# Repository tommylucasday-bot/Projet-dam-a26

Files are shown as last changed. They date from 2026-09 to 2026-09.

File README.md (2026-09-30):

# Projet-dam-a26
## Distributeur automatique modulaire :

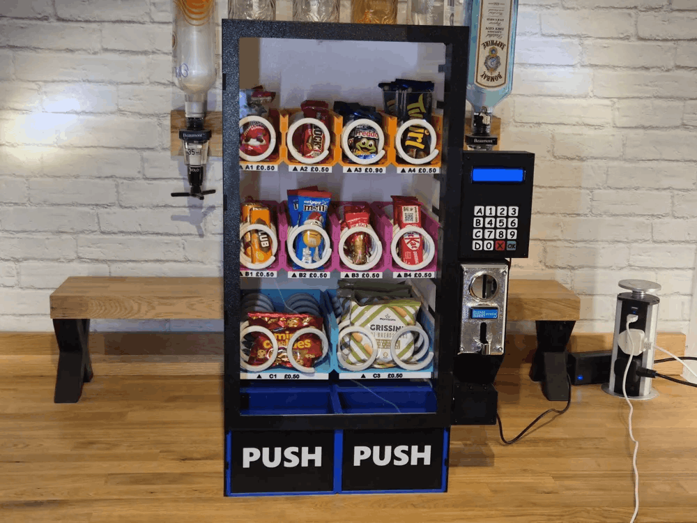
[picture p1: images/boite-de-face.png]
image-produit


### Contexte :
Dans le cadre du cours de planification de projet, nous devons réaliser un projet d’électronique pouvant être utilisé par les futurs étudiants afin de mettre en pratique diverses notions vues en classe.
### Objectif :
Ce projet a pour objectif de produire une machine distributrice automatique modulaire pouvant être personnalisée au gout du client que se sois selon la taille ou la couleur désirée mais aussi les moyens de paiements et les interfaces de contrôle désirés par celui-ci. 
### Structure du dépôt :
[Projet-dam-a26]    
- README.md  
- images  
  - Ensemble des images utilisées dans la documentation.     
- projet-original  
  - documentations  
     - Documentation originale fournie avec les fichiers originaux permettant la reproduction du projet.  
  - stl-originaux  
     - Accessoires  
       - Ensemble des fichiers 3d afin de produire les différents accessoires.  
     - Coils  
        - Ensemble des fichiers 3d afin de produire les différentes variantes de vis sans fin.  
     - Door  
       - Ensemble des fichiers 3d afin de produire les différentes pièces nécessaire pour la porte de la machine.  
     - Front Sides  
       - Ensemble des fichiers 3d afin de produire les différentes pièces nécessaire pour le devant de la machine.  
     - Keypad  
       - Ensemble des fichiers 3d afin de produire les différentes pièces nécessaire pour le clavier de la machine.  
     - Lid  
       - Ensemble des fichiers 3d afin de produire les différentes pièces nécessaire pour le couvercle de la machine.  
     - Module Sides  
       - Ensemble des fichiers 3d afin de produire les différentes pièces nécessaire pour les cotes de la machine.  
     - Modules  
       - Ensemble des fichiers 3d afin de produire les différentes pièces nécessaire pour les modules contenant les differents produits a vendre.  
- scrum  
  - carnet-de-produit  
    - Ensemble de la documentation expliquant la vision du projet et les diverses fonctionnalites prevus pour la machine.   
  - sprint-1  
    - Ensemble de la documentation expliquant l'objectif sur sprint 1, les diverses taches a effectuer et la rétroaction a la fin de celui-ci.  
  - sprint-2  
    - Ensemble de la documentation expliquant l'objectif sur sprint 1, les diverses taches a effectuer et la rétroaction a la fin de celui-ci.  
  - sprint-3  
    - Ensemble de la documentation expliquant l'objectif sur sprint 1, les diverses taches a effectuer et la rétroaction a la fin de celui-ci.  
  - LICENSE  

### Démarage
Afin de faire fonctionner le produit il suffira de le brancher a une source de tension 120v, de le remplir et d'indiquer les prix desirer pour les items a l'aide du code administrateur sur l'interface utilisateur.

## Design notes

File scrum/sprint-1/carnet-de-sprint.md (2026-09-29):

## Objectif du sprint
Concevoir un prototype fonctionnel de la machine distributrice permettant la sélection d'un produit, la gestion du paiement et la commande des différents moteur de distribution.

## Tâches 1 - Préparation du système de monnaie :
Installer le module pour le sytème de monnaie sur la machine distributrice.
Brancher et configurer le lecteur pour détecter chaque pièce insérée.
S'assurer que le détecteur de monnaie détecte bien la monnaie.

## Tâches 2 - Impression de la machine distributrice :
### Accesoires
- [ ] Imprimer l'objet : "Coin Reader"                       x1
- [ ] Imprimer l'objet : "Coin Tray"                         x1
### Coils
- [x] Imprimer l'objet : "Coil 5 Items Left Hand"            x1
- [x] Imprimer l'objet : "Coil 5 Items Right Hand"           x1
- [x] Imprimer l'objet : "Coil 6 Items Left Hand"            x1
- [x] Imprimer l'objet : "Coil 7 Items Left Hand"            x1
### Door
- [x] Imprimer l'objet : "Bottom Door Corner Hinge"          x1
- [x] Imprimer l'objet : "Door Straight Hinger"              x1
- [x] Imprimer l'objet : "Door Top Corner Hinge"             x1
- [x] Imprimer l'objet : "Door Top Corner Right"             x1
- [x] Imprimer l'objet : "Door Straight Latch"               x1
- [x] Imprimer l'objet : "Door Bottom Corner Right"          x1
- [x] Imprimer l'objet : "Door Glass Holder"                 x4
- [x] Imprimer l'objet : "Door Joiner"                       x6
### Front Sides
- [x] Imprimer l'objet : "Front Side Bottom Right"           x1
- [x] Imprimer l'objet : "Front Side Bottom Hinge"           x1
- [x] Imprimer l'objet : "Front Side Hinge v2"               x2
- [x] Imprimer l'objet : "Front Side Right Door Latch"       x1
- [x] Imprimer l'objet : "Front Side Right"                  x1
- [x] Imprimer l'objet : "Front Side Joiner Plate"           x4
- [x] Imprimer l'objet : "Joiner Front Side to Module Side"  x10
### Lid
- [x] Imprimer l'objet : "Front Lid Edge v2"                 x2
- [x] Imprimer l'objet : "Front Lid plate"                   x1
- [x] Imprimer l'objet : "Lid Edge v2"                       x2
- [x] Imprimer l'objet : "Lid Plate"                         x1
- [x] Imprimer l'objet : "Plate Joiner"                      x1
### Module sides
- [x] Imprimer l'objet : "Bottom Module Side"                x2
- [x] Imprimer l'objet : "Module Side"                       x4
### Module
- [x] Imprimer l'objet : "Back Stand"                        x2
- [x] Imprimer l'objet : "Double Label"                      x1
- [x] Imprimer l'objet : "Double Module"                     x1
- [x] Imprimer l'objet : "Module Joiner"                     x2
- [x] Imprimer l'objet : "Single Modules"                    x2
- [x] Imprimer l'objet : "Single Label"                      x2
- [x] Imprimer l'objet : "Push Bin"                          x1
- [x] Imprimer l'objet : "Push Flap"                         x1
- [x] Imprimer l'objet : "Single Back Plate"                 x2
- [x] Imprimer l'objet : "Single Back Plate Top"             x2
### Bonus Parts
- [x] Imprimer l'objet : "Adapteur Servo"                    x4
- [ ] Imprimer l'objet : "Adapteur Servo Connect"            x4

## Tâches 3 - Organisation des moteurs :
Fixer les moteurs de distribution et les ressorts sur leurs supports.
Cabler les moteurs aux circuits de commandes.
Programmer pour etre capable de faire tourner le moteur selon la distance voulue.

## Tâches 4 - Interface d'utilisateur :
Installer l'écran sur la machine distributrice et faire afficher la liste des produits et les prix.
Faire afficher un ecran d'acceuil de base pour le client.

## Tâches 5 - Relié les différentes taches pour obtenir un prototype fonctionnel :
Faire en sorte que les différents composants des tâches fonctionnent entre elle pour permettre une démo lors de la fin du sprint 1.

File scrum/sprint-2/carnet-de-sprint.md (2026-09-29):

## Tâches 1 - programmation du payement par carte :
Configurer le module de paiement pour compter les pièces ou lire la carte.
Calculer le total du crédit entré par l'utilisateur.
Gérer le rejet de la pièce ou le retour de monnaie si le montant dépasse le prix.
Ajouter un voyant lumineux et un signal sonore pour guider l'utilisateur.

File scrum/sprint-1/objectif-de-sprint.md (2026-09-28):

# Objectif de sprint

## Vision globale
Notre objectif est de reconstruire la machine distributrice en utilisant une imprimante 3d et de pouvoir la faire fonctionner.

## Ce qu'on veut accomplir
- Faire le boitier de la machine distributrice avec une imprimante 3d, celle-ci aura une porte avec une vitre pour pouvoir à l'intérieur.
- Faire l'impression des bacs pour les produits vendus, ressorts et ajouter des moteurs DC pour pouvoir faire tourner les ressorts pour faire dessendre les produits.
- Avoir une porte pour permettre la récupération des articles qui vont tomber.
- Avoir 3 boutons permettant la sélection des produits.
- Utilisation d'un écran affin d'afficher le prix des produits et permettre l'affichage des produits en rupture de stock
- Mettre en place un système de payment avec de la monnaie et une endroit pour stocker celle-ci.

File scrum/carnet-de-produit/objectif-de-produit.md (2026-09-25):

# Objectif de produit

## Vision globale
Notre objectif est de reconstruire la machine distributrice originale pour qu'elle fonctionne parfaitement, puis de l'améliorer pour la rendre plus pratique, autonome et facile à utiliser.

## Ce qu'on veut accomplir
- Avoir une distributrice fiable qui livre les produits sans bloquer.
- Ajouter une porte facile à ouvrir pour le remplissage et des capteurs fiables.
- Intégrer un système de paiement par carte avec des boutons de sélection.
- Brancher la machine directement sur une prise murale standard de 120 V.

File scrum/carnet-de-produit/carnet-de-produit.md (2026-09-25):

# Carnet de produit

## Sprint 1 : Projet original
- Monter et imprimer les pièces de base de la distributrice
- Faire le câblage et tester les moteurs
- Programmer le code de départ
- Faire la démonstration fonctionnelle au prof

## Sprints 2 et 3 : Nos améliorations
- Ajouter une porte sur charnières avec aimants pour faciliter le remplissage
- Mettre une plaque de pression pour détecter quand le produit tombe
- Ajouter un capteur pour avertir quand une rangée est vide
- Installer un bloc d'alimentation 120 V pour brancher dans le mur
- Ajouter un système de paiement par carte RFID
- Mettre des boutons pour sélectionner le produit
- Ajouter un écran simple pour l'utilisateur
- Mettre des pieds antidérapants pour stabiliser la machine

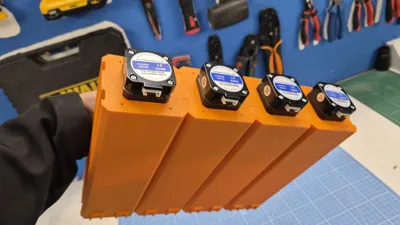
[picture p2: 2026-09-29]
images/bacs-et-moteurs.png

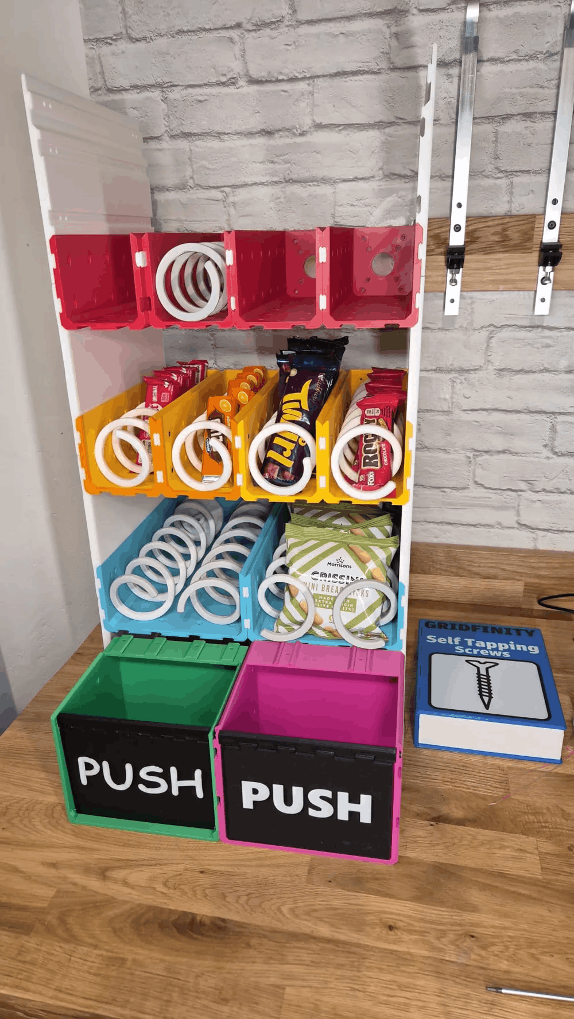
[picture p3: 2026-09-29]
images/distributeur-sans-boite.png

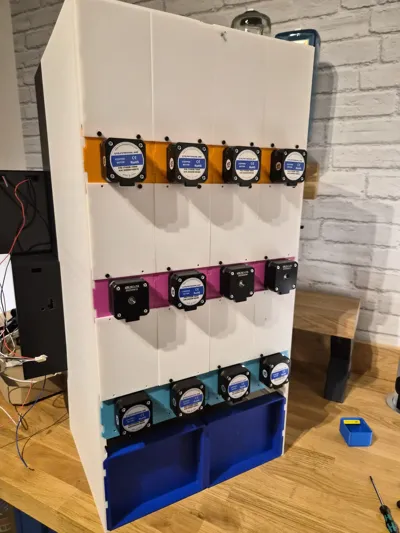
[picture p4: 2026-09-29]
images/boite-de-dos.png

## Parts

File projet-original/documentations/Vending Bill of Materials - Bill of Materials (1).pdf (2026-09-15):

Part | Type | Quantity | Price per Item | Total | Link
M2.5 x 5mm Self Tapping Screws | Fixings | 140 | £0.04 | £5.60 https://uk.store.bambulab.com/products/bt2-5-socket-head-cap-self-tapping-screws-shcs-new?id=41654799073340
M2.5 x 6mm Self Tapping Screws | Fixings | 60 | £0.04 | £2.40 https://uk.store.bambulab.com/products/bt2-5-socket-head-cap-self-tapping-screws-shcs-new?id=41654799106108
M3 x 5mm bolts | Fixings | 52 | £0.04 | £2.08 https://uk.store.bambulab.com/products/m3-button-head-cap-machine-screws-bhcs?id=41627995111484
M4 x 10mm Bolts | Fixings | 4 | £0.08 | £0.32 https://uk.store.bambulab.com/products/m4-button-head-cap-machine-screws-bhcs?id=41632981778492
m4 x 4mm Heat Inserts | Fixings | 4 | £0.06 | £0.24 https://uk.store.bambulab.com/products/round-threaded-brass-heat-insert-nut?id=41692091056188
Nema 17 Stepper Motor | Electronics | 12 | £3.72 | £44.64 https://www.omc-stepperonline.com/e-series-nema-17-bipolar-1-8deg-17ncm-24-07oz-in-1a-42x42x23mm-4-wires-17he08-1004s
DRV8825 Stepper Driver | Electronics | 12 | £1.80 | £21.60 https://www.amazon.co.uk/DRV8825-Stepper-Suitable-8-2V-45V-Printer/dp/B0CCRXGKLV/
Arduino Nano | Electronics | 2 | £3.80 | £7.60 https://www.amazon.co.uk/Binghe-Controller-Interface-Microcontroller-Compatible/dp/B0CX1B4X7M/
Arduino Nano Breakout Board | Electronics | 2 | £3.00 | £6.00 https://www.amazon.co.uk/Extension-Binghe-Expansion-Terminals-Compatible/dp/B0D86FB59B
12V Power Supply | Electronics | 1 | £14.00 | £14.00 https://www.amazon.co.uk/inShareplus-100-240V-Adapter-Voltage-Transformer/dp/B08P75KKCS/
5V Relay | Electronics | 1 | £1.75 | £1.75 https://www.amazon.co.uk/AEDIKO-Channel-Optocoupler-Isolation-Support/dp/B09M62VCGX/
Door Solenoid | Electronics | 1 | £8.00 | £8.00 https://www.amazon.co.uk/JZK-Electric-Solenoid-Assembly-Security/dp/B074MX923N
I2C Screen | Electronics | 1 | £5.50 | £5.50 https://www.amazon.co.uk/FREENOVE-Display-Compatible-Arduino-Raspberry/dp/B0B76Z83Y4/
Flat Keypad | Electronics | 1 | £6.50 | £6.50 https://www.amazon.co.uk/AZDelivery-Membrane-Keyboard-Arduino-including/dp/B07ZF7YHKC
---- OR ----- Black Keypad | Electronics | 1 | £8.00 | https://www.amazon.co.uk/Sarini-Keyboard-Compatible-Arduino-Raspberry/dp/B0D6TV2YT6
6mm x 3mm magnet | Magnets | 1 | £5.00 | £5.00 https://www.amazon.co.uk/MOXYOY-60-Piece-Small-Magnets-Whiteboards/dp/B0F3JF6BZJ
Acyrlic Sheet 2mm for Door 271 x 495mm Acyrlic | 1 | £5 | £5 https://www.simplyplastics.com/catalog/sheet/extruded-acrylic-sheet/clear-extruded-acrylic-sheet/c-24/c-84/p-240
Total | £136.23

Notes

*Many of these parts are multipacks, the total price will be cheaper if you have some of these consumables already.

**I've put no effort into finding cheapest suppliers, just first links mostly from Amazon. Go hunting on AliExpress for deals!

***I've guessed the number of self tapping screws. please round up!

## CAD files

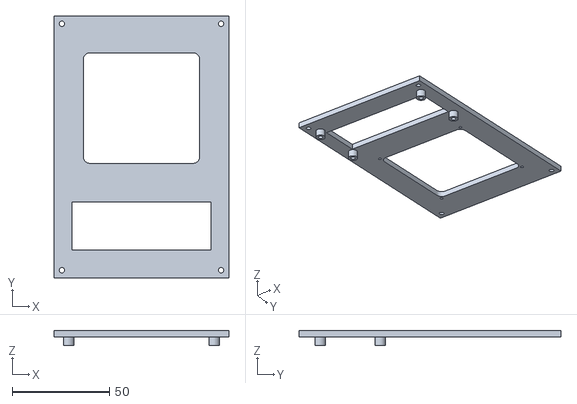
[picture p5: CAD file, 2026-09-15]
projet-original/stl-originaux/Accessories/Black Keypad Plate.stl
90.0 x 135.0 x 7.50

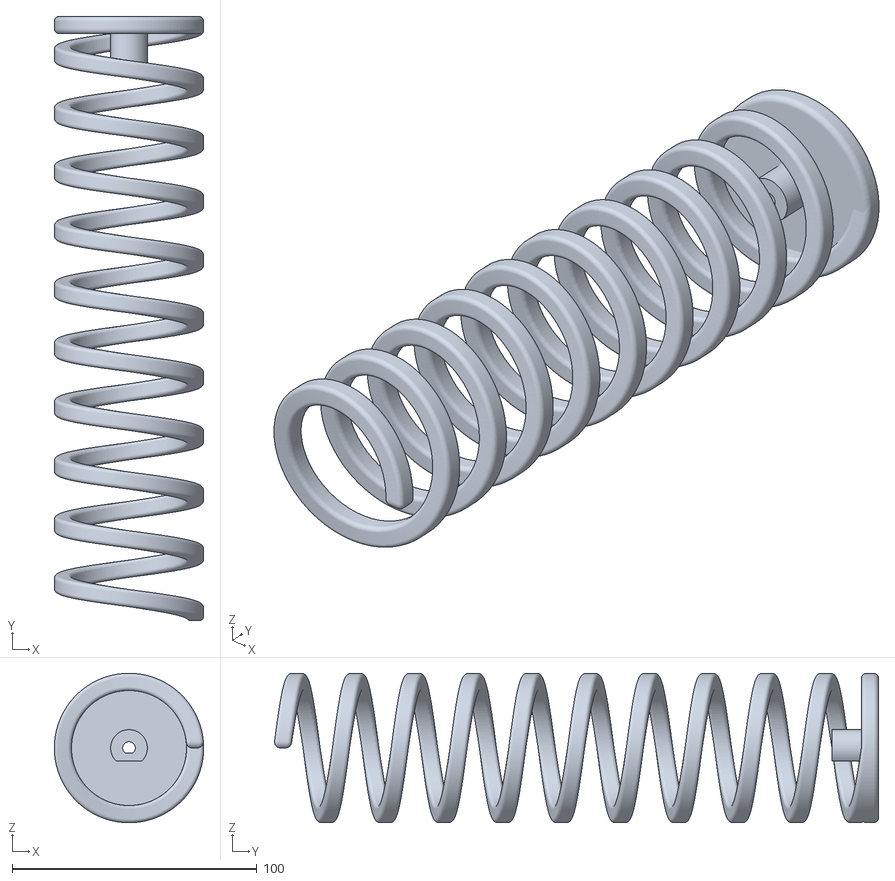
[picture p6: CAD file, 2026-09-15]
projet-original/stl-originaux/Coils/Coil 9 Items Left Hand.stl
61.0 x 246.6 x 61.0

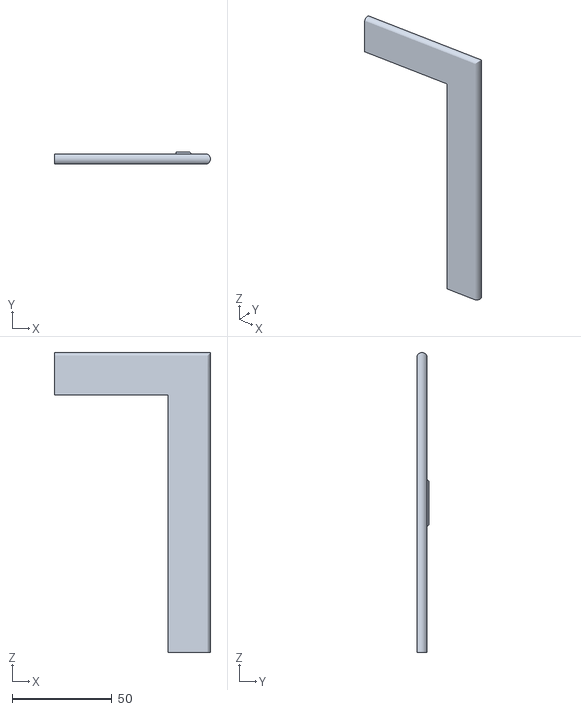
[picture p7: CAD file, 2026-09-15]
projet-original/stl-originaux/Door/Door Top Corner Right.stl
78.2 x 5.80 x 150.3

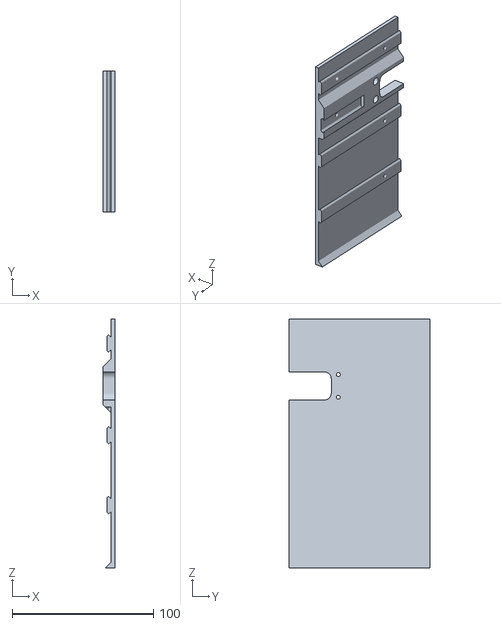
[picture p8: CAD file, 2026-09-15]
projet-original/stl-originaux/Front Sides/Front Side Right Door Latch.stl
8.50 x 100.0 x 176.4

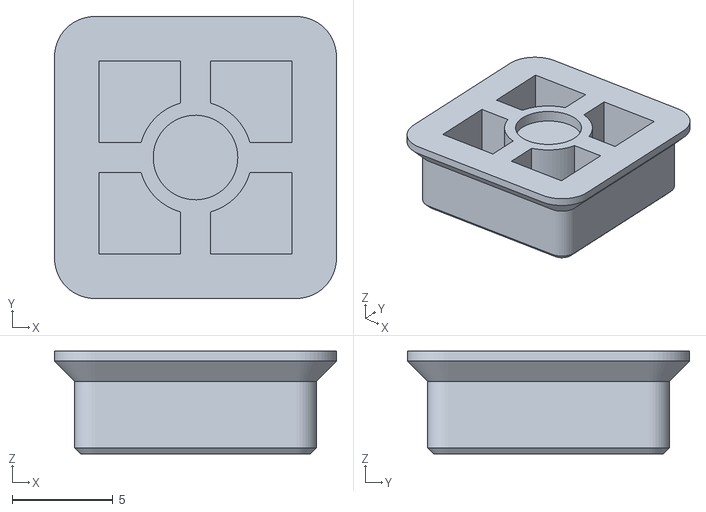
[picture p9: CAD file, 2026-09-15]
projet-original/stl-originaux/Keypad/Button 6.stl
14.0 x 14.0 x 5.10

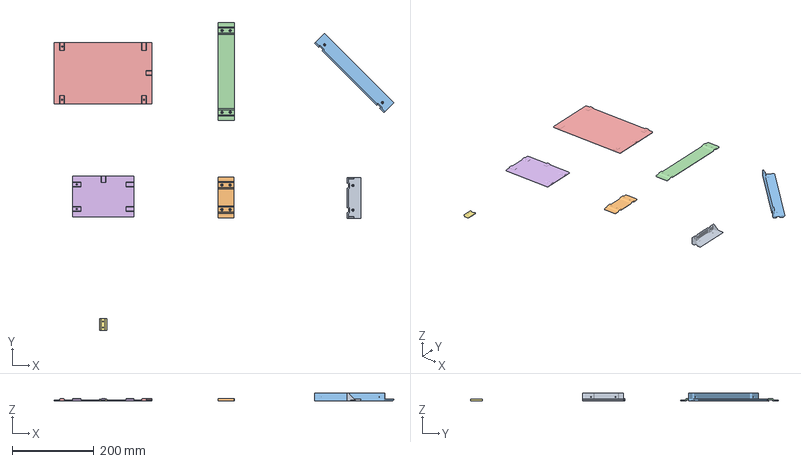
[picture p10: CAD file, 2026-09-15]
projet-original/stl-originaux/Lid/Lid.3mf
831.1 x 753.6 x 20.0 mm
Front Lid Edge.stl
Front Lid Joiner.stl
Lid Edge.stl
Lid Joiner.stl
Lid Plate.stl
Front Lid Plate.stl
Plate Joiner.stl

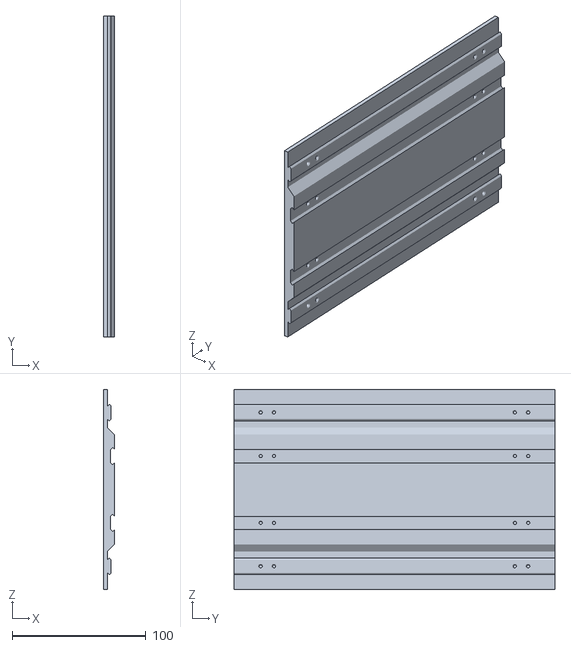
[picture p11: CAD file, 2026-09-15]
projet-original/stl-originaux/Module Sides/Module Side.stl
8.50 x 240.0 x 149.8

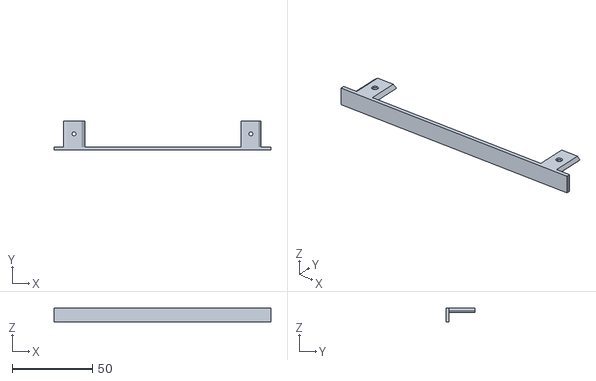
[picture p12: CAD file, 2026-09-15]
projet-original/stl-originaux/Modules/Double Label.stl
135.0 x 18.0 x 9.00

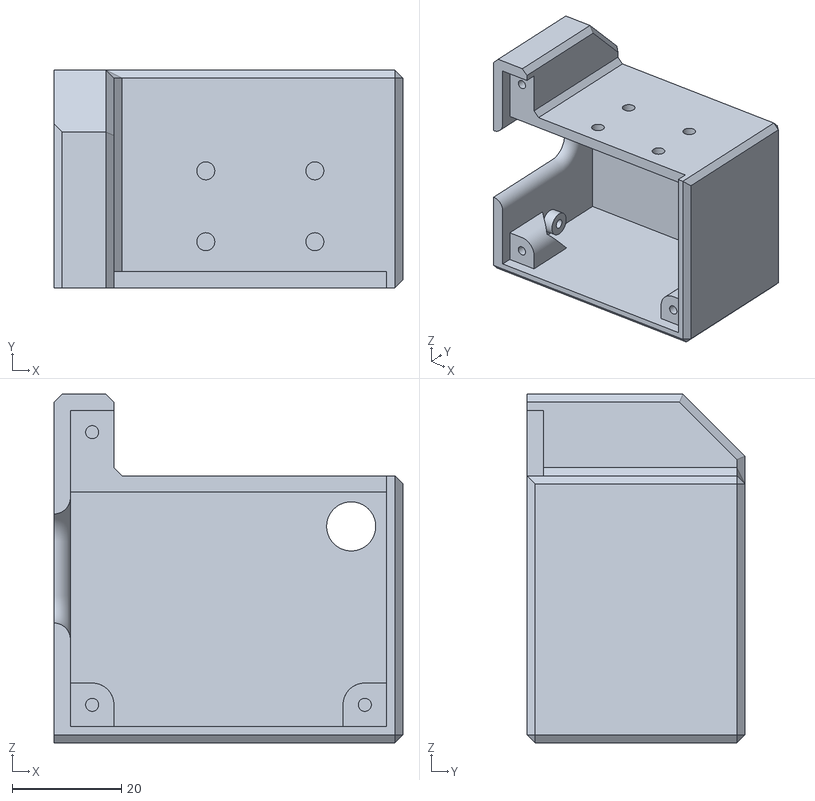
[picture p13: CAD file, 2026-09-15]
projet-original/stl-originaux/Accessories/Door solenoid.stl
64.0 x 40.0 x 64.0

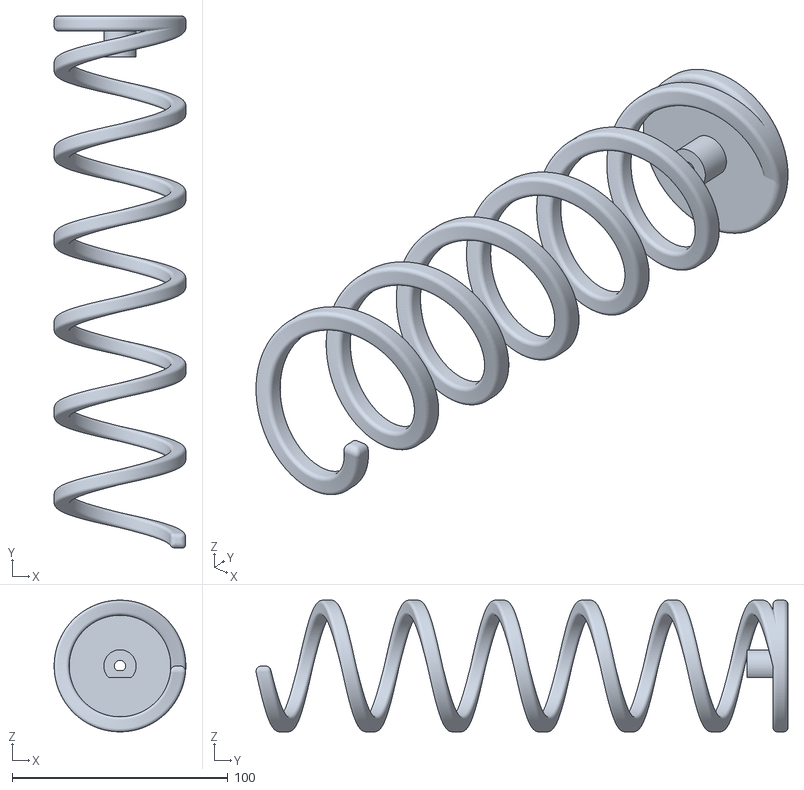
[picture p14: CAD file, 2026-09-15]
projet-original/stl-originaux/Coils/Coil 5 Items Right Hand.stl
61.0 x 246.4 x 61.0

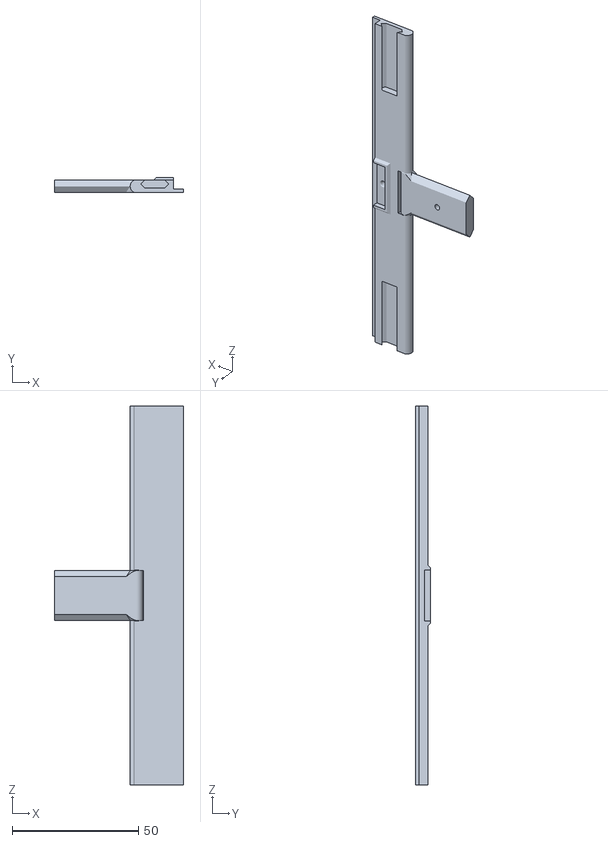
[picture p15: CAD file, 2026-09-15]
projet-original/stl-originaux/Door/Door Straight Hinge.stl
51.2 x 5.80 x 150.0

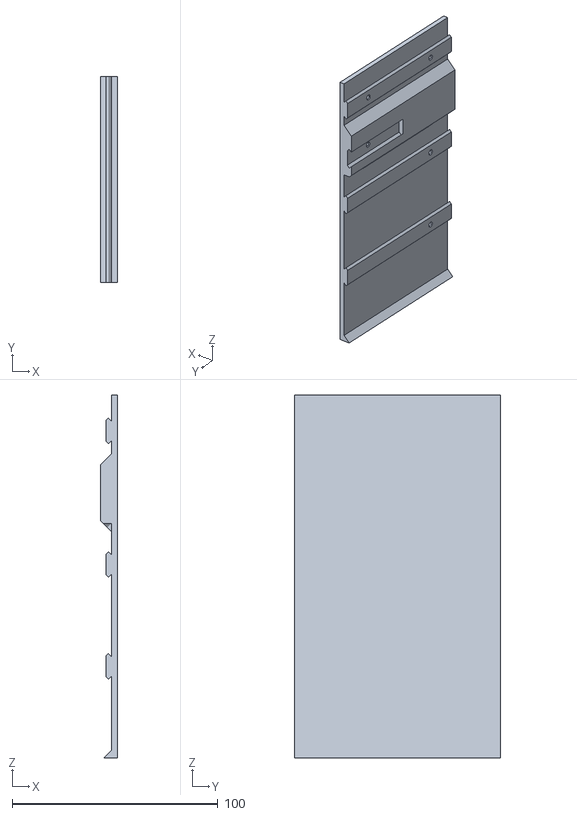
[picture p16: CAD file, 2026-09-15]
projet-original/stl-originaux/Front Sides/Front Side Bottom Right.stl
8.50 x 100.0 x 176.4

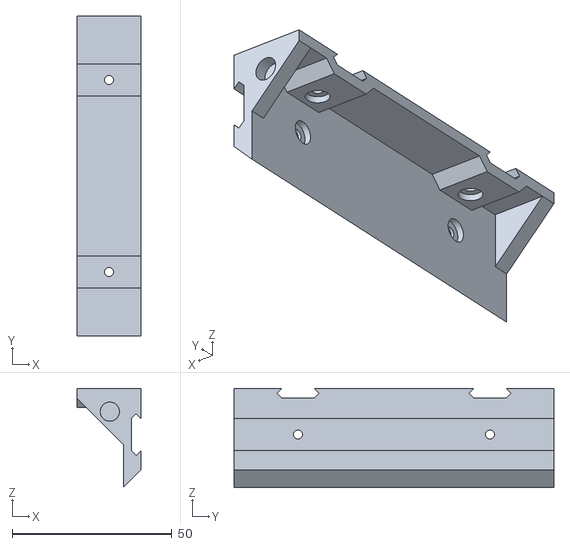
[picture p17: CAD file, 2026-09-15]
projet-original/stl-originaux/Lid/Front Lid Edge v2.stl
20.0 x 100.0 x 31.0

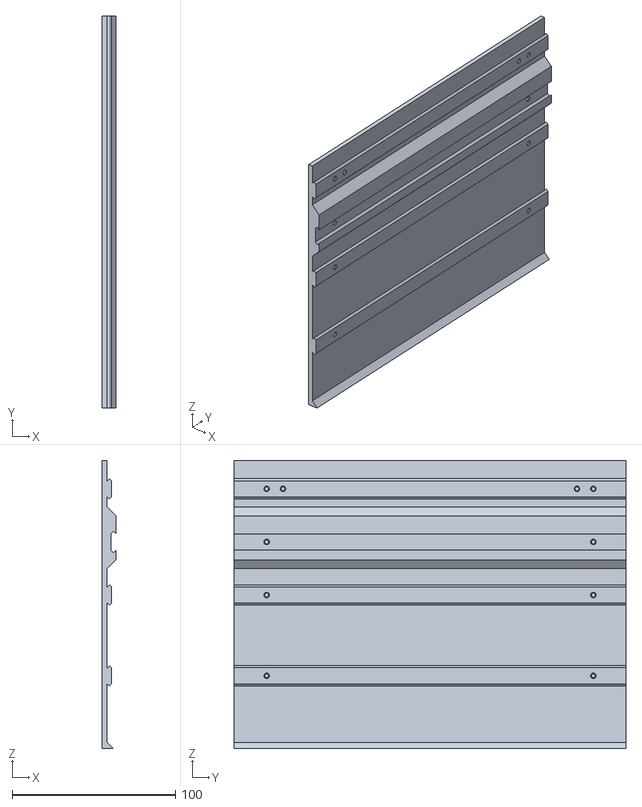
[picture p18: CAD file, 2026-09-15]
projet-original/stl-originaux/Module Sides/Bottom Module Side.stl
8.50 x 240.0 x 176.4

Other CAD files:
projet-original/stl-originaux/Keypad/Button A.stl
projet-original/stl-originaux/Modules/Push Flap Non-AMS.stl
projet-original/stl-originaux/Accessories/Accessories.3mf
projet-original/stl-originaux/Coils/Coils.3mf
projet-original/stl-originaux/Accessories/Coin Reader.stl
projet-original/stl-originaux/Accessories/Coin Tray.stl
projet-original/stl-originaux/Accessories/Door solenoid Cover.stl
projet-original/stl-originaux/Accessories/Flat Keypad Plate.stl
projet-original/stl-originaux/Coils/Coil 5 Items Left Hand.stl
projet-original/stl-originaux/Coils/Coil 6 Items Left Hand.stl
projet-original/stl-originaux/Coils/Coil 6 Items Right Hand.stl
projet-original/stl-originaux/Coils/Coil 7 Items Left Hand.stl
projet-original/stl-originaux/Coils/Coil 7 Items Right Hand.stl
projet-original/stl-originaux/Coils/Coil 8 Items Left Hand.stl
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

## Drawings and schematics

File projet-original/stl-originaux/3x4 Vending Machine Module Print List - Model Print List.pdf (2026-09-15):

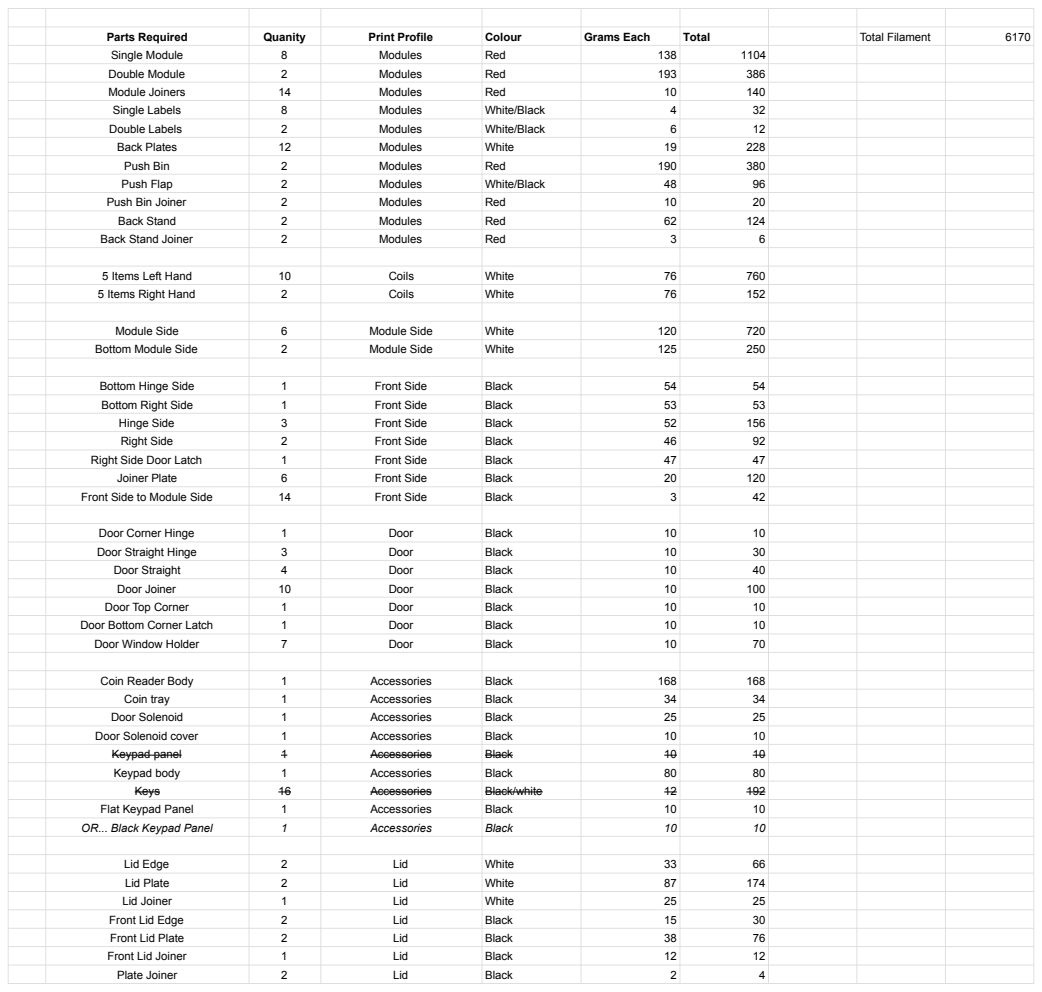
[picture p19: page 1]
Parts Required; Quanity; Print Profile; Colour; Grams Each; Total; Total Filament; Single Module; Modules; Red; Double Module; Module Joiners; Single Labels; White/Black; Double Labels; Back Plates; White; Push Bin; Push Flap; Push Bin Joiner; Back Stand; Back Stand Joiner; 5 Items Left Hand; Coils; 5 Items Right Hand; Module Side; Bottom Module Side; Bottom Hinge Side; Front Side; Black; Bottom Right Side; Hinge Side; Right Side; Right Side Door Latch; Joiner Plate; Front Side to Module Side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

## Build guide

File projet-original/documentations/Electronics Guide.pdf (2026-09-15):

# Vending Machine Electronics Instructions

## 1. Overview

This document explains the electronics used in a DIY vending machine. You do not need to be an electronics expert to follow this but ideally some competency with Arduino is required. This document isn't a definitive guide, you can wire this however you want this is just an idea of how I approach it.

The vending machine electronics are based around:

- 12 V DC power for motors and solenoids
- An Arduino Nano as the main controller, another Arduino Nano used to control the motors.
- Modular wiring so parts can be built and tested independently

At the time of release, you have to make the boards yourself. It could be breadboard or made with proto board. I've provided gerber files but these are currently untested. I will be creating these as a kit of parts in the future.

## 2. High‑Level System Layout

To keep things simple and reliable, the machine is split into two main electronics boards:

### 2.1 Motor Control Board (Back of Machine)

This board is responsible only for dispensing items.

It contains:

- Arduino Nano
- Stepper motor drivers (DRV8825)
- Connectors for NEMA 17 stepper motors
- 12 V power input

This board:

- Does not handle user input
- Does not control the display
- Only receives simple commands like: “Dispense motor 3”

### 2.2 Control / Interface Board (Front of Machine)

This board handles everything the user interacts with:

- Keypad (button matrix)
- Screen (I2C)
- Door solenoid
- Coin counter

It also contains:

- Arduino Nano

The two boards communicate using serial (TX/RX).

Why split it this way?

- Easier to wire
- Easier to debug
- Less electrical noise from motors near sensitive inputs
- You can upgrade or replace one board without touching the other

### 2.3 Alternative

You could get a larger Arduino like a ESP32 or Arduino Mega and wire everything to it! It'll take more wiring, but remove the complexity of the serial comms between 2 boards.

## 3. Power System (12 V Everywhere)

### 3.1 Why 12V?

12 V is recommended for the entire machine because:

- Stepper motors work well at 12 V
- Door latch solenoids are commonly 12 V
- Power supplies are cheap and widely available

### 3.2 Logic Power

- The Arduino Nano is powered from 12 V via its VIN pin.All grounds (GND) are connected together
- Most Arduino Nanos run on 5V logic. Do not connect 12V to any arduino pin or it will break it instantly.

## 4. Controlling Stepper Motors (NEMA 17 + DRV8825)

Every dispensing mechanism in the machine uses a NEMA 17 stepper motor.

### 4.1 What is a Stepper Motor?

A stepper motor moves in small precise steps instead of spinning freely like a DC motor. This makes it ideal for vending machines because:

- You can control exact movement
- No position sensors are required
- Motors stop holding position when powered

### 4.2 Motor Type

- NEMA 17 bipolar stepper motors
- 4‑wire motors

⚠️ Always check the wire colour pairs – different manufacturers use different colours.

### 4.3 DRV8825 Stepper Driver (Standard Wiring)

The DRV8825 is a popular stepper driver module.

Normally it is wired with:

- STEP pin → Arduino
- DIR pin → Arduino
- ENABLE pin → Arduino (optional)
- Microstep pins (M0/M1/M2)

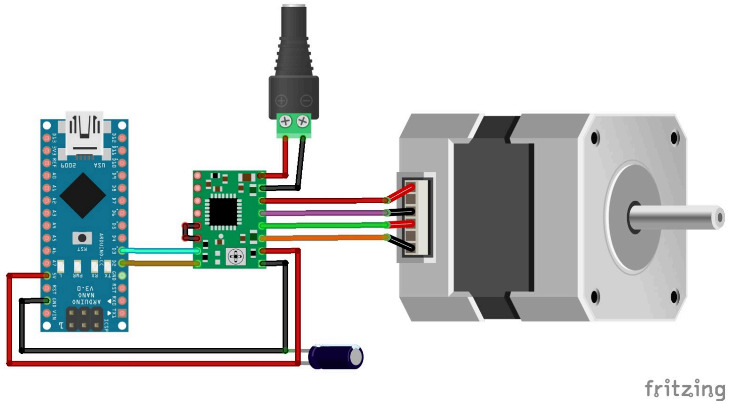
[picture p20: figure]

### 4.4 Simplified "Cheat" Wiring Method (Recommended)

To reduce wiring complexity:

- All STEP pins are tied together
- DIR pins are not used (single direction only)
- Each motor has its own ENABLE pin

This means:

- One Arduino pin generates step pulses for all motors
- Individual motors are selected by enabling one driver at a time
- You’ll only need 1 pin per motor, plus 1 pin for the step signal. Eg 16 motors = 17 pins.

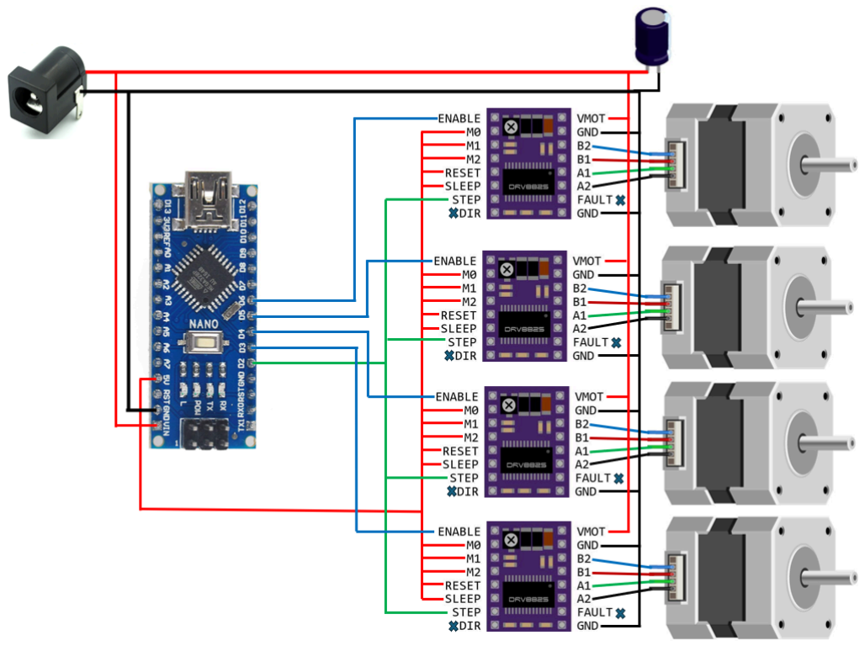
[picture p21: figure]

### 4.5 Microstepping

Microstepping allows smoother motion and quieter motors.

It is controlled using the M0 / M1 / M2 pins on the DRV8825.

Example:

- M0 = HIGH
- M1 = HIGH
- M2 = HIGH

This gives 1/32 microstepping.

⚠️ At 1/32 microstepping:

- One full motor rotation = 6400 steps (instead of 200)

Higher microstepping:

- Smoother motion
- Less vibration
- Slightly reduced torque

### 4.6 Powering the Motors

- Motor supply: 12 V
- Set the current limit on each DRV8825 before connecting motors

How to set output current limit on A4988 stepper driver (https://www.youtube.com/watch?v=AVlee67TQxs)

I set each motor to 1.2A, so VREF = 0.6V on the multimeter.

⚠️ Never plug or unplug stepper motors while powered – it can destroy the driver.

### 4.7 Controlling Steppers in Code (AccelStepper)

To simplify motion control, the AccelStepper Arduino library is used.

Basic example (single shared STEP pin, individual ENABLE pins):

#include <AccelStepper.h>

#define STEP_PIN 2

#define ENABLE_A1 3

AccelStepper stepper(AccelStepper::DRIVER, STEP_PIN, STEP_PIN);

void setup() {
pinMode(ENABLE_A1, OUTPUT);
digitalWrite(ENABLE_A1, LOW); // enable motor

stepper.setMaxSpeed(2000); stepper.setAcceleration(1000);

}

void loop() {
stepper.move(6400); // one full rotation at 1/32 microstepping stepper.runToPosition();

digitalWrite(ENABLE_A1, HIGH); // disable motor after dispense delay(2000);
}

Only one motor is enabled at a time, ensuring only the selected spiral turns.

## 5. Keypad (Button Matrix)

To reduce wiring, the keypad is wired as a matrix (rows and columns) instead of one wire per button. This reduces the pins required from 16 to 8, and adding another row only adds 1 more pin.

### 5.1 Wiring (Example)

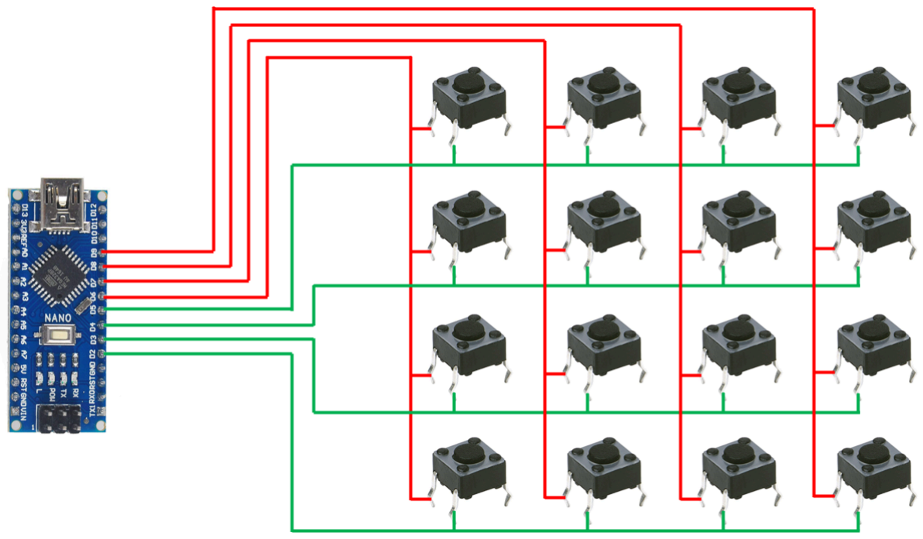
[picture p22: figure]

### 5.2 Code Snippet (Keypad Library)

This is the simplest way for beginners.

#include <Keypad.h>

const byte ROWS = 4;
const byte COLS = 4;

char keys[ROWS][COLS] = {
{'1','2','3','A'},
{'4','5','6','B'},
{'7','8','9','C'},
{'*','0','#','D'}
};
byte rowPins[ROWS] = {2, 3, 4, 5}; | // wire to the row pins
byte colPins[COLS] = {6, 7, 8, 9}; | // wire to the column pins

Keypad keypad = Keypad(makeKeymap(keys), rowPins, colPins, ROWS, COLS);

void setup() {
Serial.begin(115200);
}

void loop() {
char key = keypad.getKey(); if (key) {
Serial.print("Key pressed: "); Serial.println(key);
}
}

## 6. Screen (I2C)

The screen uses I2C which keeps wiring simple (only 4 wires).

### 6.1 Wiring

- VCC → 5 V (or 3.3 V depending on your display)
- GND → GND
- SDA → Arduino SDA
- SCL → Arduino SCL

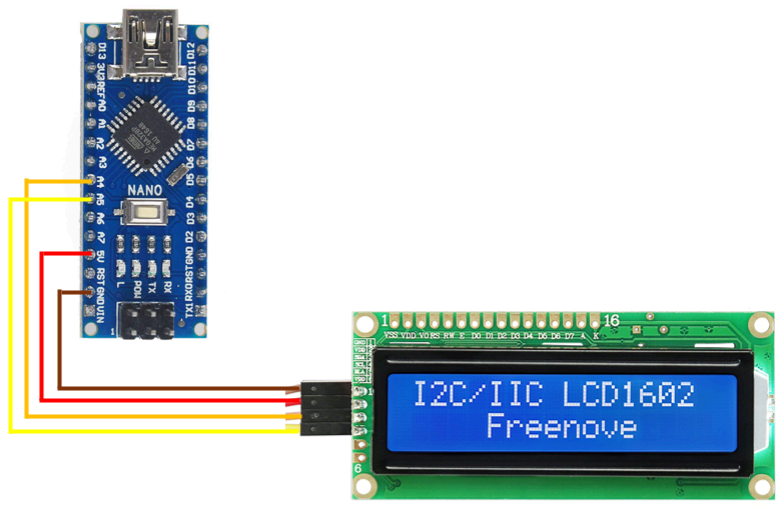
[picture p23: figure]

### 6.2 Code Snippet (I2C LCD Example)

For the common 16x2 / 20x4 I2C LCD backpacks:

#include <Wire.h>

#include <LiquidCrystal_I2C.h>

LiquidCrystal_I2C lcd(0x27, 16, 2); // address may be 0x27 or 0x3F

void setup() {
lcd.init();
lcd.backlight();
lcd.setCursor(0, 0);
lcd.print("Vending Machine"); lcd.setCursor(0, 1);
lcd.print("Insert coin...");
}

void loop() {
}

Tip: If nothing shows, your I2C address is probably different. Use an “I2C scanner” sketch to find it.

## 7. Door Lock Solenoid (12 V)

The door lock uses a 12 V DC solenoid (sometimes called a door latch / door strike).

### 7.1 Why a Solenoid?

- Simple
- Reliable
- Strong holding force

### 7.2 Driving the Solenoid (Important)

Solenoids are inductive loads and must never be driven directly from an Arduino pin.

Use a breakout relay board which lets you put logic (5v) in, and switch the high current solenoid.

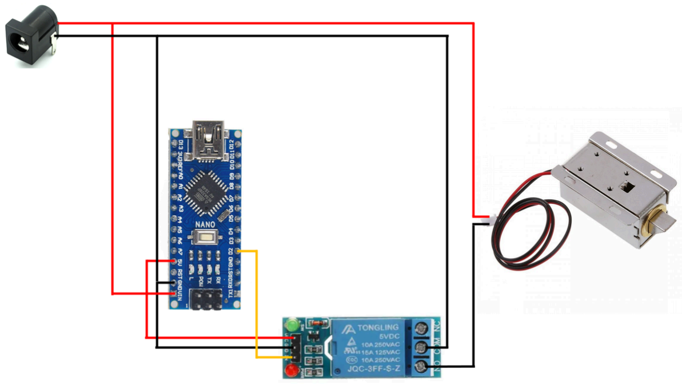
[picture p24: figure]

### 7.3 Code Snippet (Solenoid Output)

This assumes your driver circuit makes the solenoid turn on when the Arduino pin is HIGH.

const int SOLENOID_PIN = 10;

void setup() {
pinMode(SOLENOID_PIN, OUTPUT); digitalWrite(SOLENOID_PIN, LOW); }

void loop() {

// Example: unlock for 500ms digitalWrite(SOLENOID_PIN, HIGH); delay(500);
digitalWrite(SOLENOID_PIN, LOW);

delay(3000);
}

## 8. Coin Counter

Most coin acceptors output pulses (a short on/off signal) for each valid coin.

- Each pulse = one coin event
- Some acceptors output different pulse counts per coin value (e.g. £1 = 1 pulse, £2 = 2 pulses)

### 8.1 Wiring

- Coin acceptor signal output → Arduino digital input
- Common GND between coin acceptor and Arduino

### 8.2 Code Snippet (Interrupt Pulse Counting)

This example counts pulses using an interrupt and a simple debounce.

const int COIN_PIN = 2; // use an interrupt-capable pin on Nano (D2 or D3)

volatile unsigned long coinPulses = 0;
volatile unsigned long lastPulseMs = 0;

void onCoinPulse() {
unsigned long now = millis();
if (now - lastPulseMs > 20) { // debounce (adjust to suit) coinPulses++;
lastPulseMs = now;
}
}

void setup() {
Serial.begin(115200);
pinMode(COIN_PIN, INPUT_PULLUP); attachInterrupt(digitalPinToInterrupt(COIN_PIN), onCoinPulse, FALLING); }

void loop() {

static unsigned long lastPrint = 0;

if (millis() - lastPrint > 500) { lastPrint = millis();

noInterrupts();
unsigned long p = coinPulses; interrupts();

Serial.print("Coin pulses: "); Serial.println(p);
}
}

## 9. Serial Communication Between Boards

The two Arduino boards communicate using UART serial.

- TX → RX
- RX → TX
- Common GND

Example messages:

- DISPENSE A3
- DONE A3
- ERROR JAM A3

This keeps the system modular and easy to debug.

## 10. Final Notes for Beginners

- Build and test one section at a time
- Start with motors only
- Then keypad + screen
- Then solenoid
- Then coin acceptor

If something doesn’t work:

- Check power first
- Then wiring
- Then software

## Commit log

2026-09-15 Ajout des fichiers STL originaux
    [Accessories.3mf, Back Stand Joiner.stl, Back Stand.stl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]
2026-09-15 Ajout des fichiers images et documentation
2026-09-15 creation des fichier sprint 2 et 3
2026-09-25 modification des titres des fichiers
2026-09-25 Ajout carnet de produit simple
2026-09-25 modification objectif de produit
2026-09-28 Objectif de sprint 1
2026-10-27 Update retro-de-sprint.md
    jai pris le modele du prof pour le retro sprint 1, je vais le modifier par la suite pour notre projet (:
2026-10-27 Update retro-de-sprint.md
    modification
2026-10-27 Update retro-de-sprint.md
    update final
